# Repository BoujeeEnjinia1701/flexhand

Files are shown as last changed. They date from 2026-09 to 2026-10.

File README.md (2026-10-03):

# FlexHand

     

**Area:** BioMedical · **TRL:** 3 of 9 (proof of concept on paper) · **Value-engineering target:** USD 500 (estimated cost USD 305) · **Difficulty:** 4 of 5

Soft-actuated finger exoskeleton for continuous passive motion, driven by tendons from a wrist-mounted motor pack.

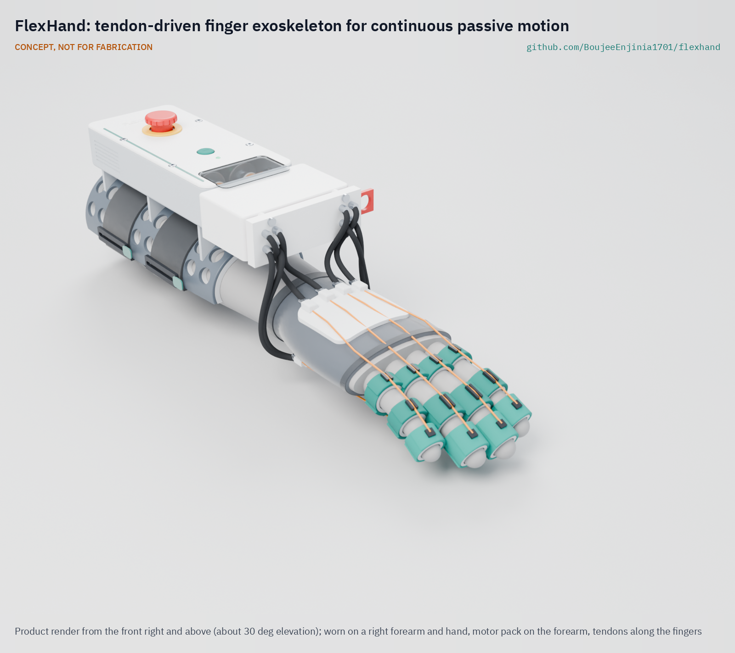
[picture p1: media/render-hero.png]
FlexHand: tendon-driven finger exoskeleton for continuous passive motion, product render


[Exploded render](media/render-exploded.png) · [Detail render](media/render-detail.png) · [Interactive 3D model](media/viewer.html) · [Concept blueprint (PDF)](media/concept-blueprint.pdf) · [General arrangement (PDF)](cad/drawings/FXH-DWG-001.pdf) · [Sizing calculations](docs/04-calcs/01-sizing.md) · [Prototype build plan](docs/05-build-plan.md) · [Design decisions](docs/06-design-decisions.md) · [Review note](docs/REVIEW.md)

## Concept rationale

Repetition is the scarce input in hand rehabilitation after stroke, and the scarce resource that delivers it is therapist time. A device that moves the fingers slowly through a therapist-set range, hundreds of times per session, can add dose at home without adding therapist hours. Tendons pulled through Bowden sheaths from a forearm pack keep the hand side light (about 117 g) and put the motors, cells and electronics where their mass matters least, which is why FlexHand uses tendons rather than a pneumatic glove or motors on the hand.

FlexHand is open and garage-buildable because the users who most need low-cost dose are least served by clinic-bound robotic gloves. Two off-the-shelf gearmotors, carrier-board electronics, 3D-printed TPU and PETG parts and bicycle shift housing keep the parts cost near USD 305 and let a research group, a clinic workshop or a makerspace build, inspect and adapt it. Openness also lets others check the safety layers (current limit, breakaway couplings, hardware stop and tool-free release) rather than trusting them. It is a research and educational prototype, not a medical device.

## Burning platform

Stroke is common, rising and concentrated where rehabilitation is thinnest. The Global Burden of Disease study counted 11.9 million new strokes and 93.8 million people living after a stroke in 2021, up 70 % and 86 % since 1990, with more than three-quarters of those affected living in low- and middle-income countries ([IHME, on the GBD 2021 stroke analysis in *The Lancet Neurology*, 2024](https://www.healthdata.org/news-events/newsroom/news-releases/lancet-neurology-air-pollution-high-temperatures-and-metabolic)). In many of those settings there are fewer than 10 skilled rehabilitation practitioners per million people ([WHO rehabilitation fact sheet](https://www.who.int/news-room/fact-sheets/detail/rehabilitation)).

Even where therapists are available, the dose is small. An observational study of 312 therapy sessions found an average of 32 repetitions of upper-limb functional movement per session, against the 400 to 600 repetitions per session used in animal studies of motor skill learning ([Lang et al., *Archives of Physical Medicine and Rehabilitation*, 2009](https://www.archives-pmr.org/article/S0003-9993(09)00353-0/abstract); [open copy, Marquette University](https://epublications.marquette.edu/cgi/viewcontent.cgi?httpsredir=1&article=1073&context=phys_therapy_fac)).

## Where it could be used

### By industry

| Industry | Use |
| --- | --- |
| Rehabilitation research | An open, instrumented platform for studies of passive-motion dose, speed and dwell, with logged cycle counts and motor current |
| Community and home rehabilitation services | A research prototype for supervised home programs, set up by a therapist and run by a care partner |
| Occupational and physical therapy education | A teaching device for tendon mechanics, joint range and the safety layers of powered orthoses |
| Assistive technology makerspaces | A documented build that local workshops can adapt to a hand, a glove size or local parts |
| Wearable robotics and medical device R&D | A low-cost reference design for tendon routing, balance pulleys and cuff pressure checks |

### By country or region

| Country or region | Why it matters there |
| --- | --- |
| United States | More than 795,000 people have a stroke each year, and stroke is a leading cause of serious long-term disability ([CDC](https://www.cdc.gov/stroke/data-research/facts-stats/index.html)); home programs could extend short outpatient courses. |
| Canada | Continuous passive motion was conceived at the Hospital for Sick Children in Toronto and has since been translated into clinical use around the world ([Canadian Medical Hall of Fame](https://www.cdnmedhall.ca/laureates/robertsalter)); an open device lets research groups in the country where the idea began build on it. |
| China | An upper-middle-income country among the low- and middle-income countries that carry more than three-quarters of the global stroke burden ([IHME](https://www.healthdata.org/news-events/newsroom/news-releases/lancet-neurology-air-pollution-high-temperatures-and-metabolic)); a large domestic electronics and motor supply base suits locally built open devices. |
| India | A WHO Systematic Assessment of Rehabilitation Situation review found that stroke units are clustered in metropolitan cities and tertiary centers and nearly absent at primary and secondary facilities ([Handa et al., *Current Physical Medicine and Rehabilitation Reports*, 2023](https://link.springer.com/article/10.1007/s40141-023-00418-2)); supervised home dose could reach people far from those centers. |
| Sub-Saharan Africa (for example Nigeria or Kenya) | Many low- and middle-income settings have fewer than 10 skilled rehabilitation practitioners per million people ([WHO](https://www.who.int/news-room/fact-sheets/detail/rehabilitation)), so each therapist's time must go further. |
| Brazil | In the 2019 National Health Survey, only 24.6 % of people who had had a stroke reported access to rehabilitation, and 73.4 % of those with activity limitations had received no physiotherapy ([Silva et al., *Arquivos de Neuro-Psiquiatria*, 2024](https://pmc.ncbi.nlm.nih.gov/articles/PMC11661889/)); a low-cost device that local university groups can build and study fits that gap. |

## What sparked the idea

The idea traces back to continuous passive motion, the concept Robert Salter developed in 1978 at the Hospital for Sick Children in Toronto after seeing how immobilization after surgery prolonged pain and recovery ([Canadian Medical Hall of Fame](https://www.cdnmedhall.ca/laureates/robertsalter)). His concept has since been translated into clinical applications around the world. FlexHand asks what that principle looks like as a light, open, wearable device that moves four fingers at home, within limits a therapist sets.

## Problem

Post-stroke hand rehab needs many repetitions, but therapist time is limited.

Problem statement: [docs/01-problem.md](docs/01-problem.md)

## Concept

Soft-actuated finger exoskeleton for continuous passive motion, driven by tendons from a wrist-mounted motor pack.

A fingerless glove carries TPU cuffs on the four fingers. Two gearmotors lying along the forearm in a strapped-on pack each turn a two-groove spool that pulls the flexor tendons of a finger pair while paying out the extensor tendons, through Bowden sheaths that cross the wrist. A floating balance pulley shares each spool line equally between the two fingers of a pair, and an open-tip fingertip thimble shares the extensor load with the finger cuff. The TRL 3 calculations give about 445 finger cycles per hour at full speed, about 3.8 sessions of 60 min per charge, cuff pressures of 40 kPa or less on a medium hand and an estimated USD 304.90 in parts, USD 195.10 under the USD 500 value-engineering target. One requirement is not met (forearm pack mass, about 712 g against 450 g), and two are at risk (gearbox rating and force-limit friction spread); see the [sizing calculations](docs/04-calcs/01-sizing.md) and the [review note](docs/REVIEW.md).

Full design precis: [docs/02-concept.md](docs/02-concept.md)

## Key components

- Two 25 mm 227:1 gearmotors with encoders, antagonistic spools and idlers
- Bowden sheaths and UHMWPE tendons, with balance pulleys, ball-detent breakaway couplings, stop beads and a pull-out release plate
- Fingerless glove, TPU finger cuffs and fingertip thimbles, dorsal and palmar plates, thumb spacer
- Motor drivers with current sensing for force limiting
- ESP32-S3 controller with a 5 V regulator, 2S Li-ion pack, emergency stop

The priced bill of materials is in [bom/bom.csv](bom/bom.csv). The parametric model is `cad/src/model.py` (STEP and STL in `cad/step` and `cad/stl`).

## Building the prototype

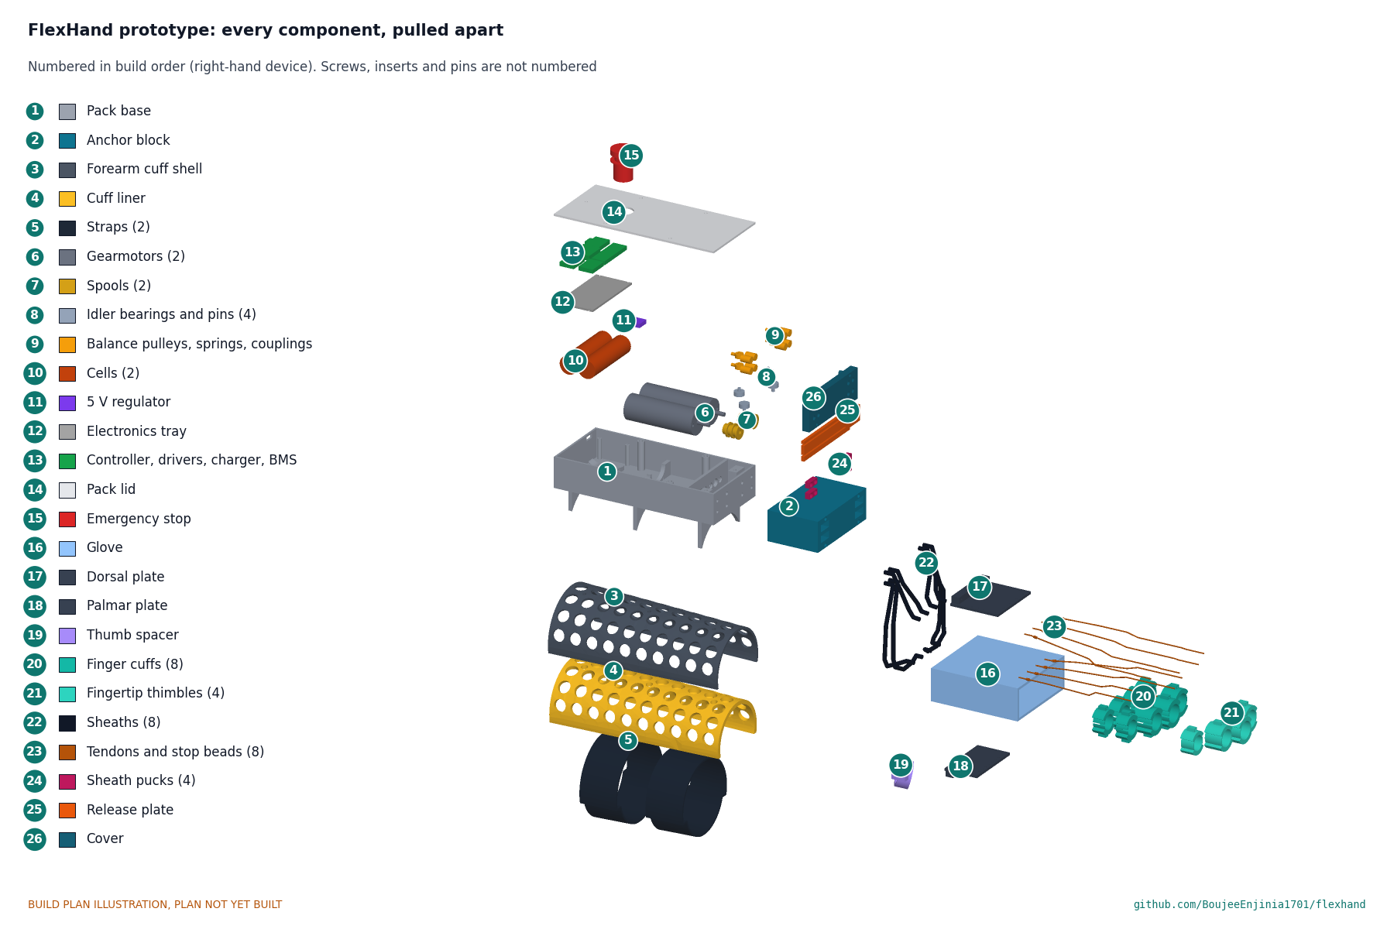
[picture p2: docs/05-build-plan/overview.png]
FlexHand prototype: every component, pulled apart and numbered in build order


The [prototype build plan](docs/05-build-plan.md) shows how to make each of the 26 components and put them together in 15 illustrated steps, with first checks and safety stops; it is a plan, not a record of a build. Drawing it made the design constructable: the pack is now screwed to the cuff, the motors sit in a printed bulkhead, the electronics sit on a tray, and a longer anchor block holds the balance pulleys and breakaway couplings, with a pull-out plate as the tool-free release ([FXH-DDR-003](docs/decisions/0003-design-for-construction.md)). Decisions still open are kept in the [design decisions register](docs/06-design-decisions.md).

## Safety

> This is a research and educational prototype. It is not a medical device, has not been cleared or approved by any regulator, and must not be used to diagnose, treat or monitor any person.

> **Safety:** The device applies force to fingers that may be spastic or insensate, its gearboxes cannot be back-driven, and it carries a lithium-ion pack. See the safety section of the [design precis](docs/02-concept.md) before building or wearing anything.

## Repository layout

| Folder | Contents |
| --- | --- |
| `docs/` | Problem, concept, requirements, calculations and design decisions |
| `cad/src/` | build123d Python source, the source of truth for all geometry |
| `cad/step/`, `cad/stl/` | Exported models for FreeCAD, other CAD tools and printing |
| `cad/drawings/` | 2D sketches and dimensioned drawings |
| `bom/` | Bill of materials |
| `electronics/` | KiCad schematics and PCB layouts |
| `firmware/` | Microcontroller code |
| `media/` | Renders, perspectives and photos |
| `build-log/` | Dated prototyping notes |

## Documentation

Controlled documents follow the portfolio [documentation standard](.kit/STANDARDS.md). Each carries a document ID (FXH-PRC-001 for the precis), a version and a revision history. Branded PDFs are built with `python .kit/render.py` and attached to GitHub Releases when a document is tagged, for example `FXH-PRC-001/v1.0`.

## Credits

Designed by Amish Chadha, with contributions from Dr. Geeti Chadha. See [CONTRIBUTORS.md](CONTRIBUTORS.md) for roles. To cite this design, use [CITATION.cff](CITATION.cff) (GitHub shows it as "Cite this repository").

AI assistance (Claude) was used to accelerate concept renders, prototype documentation and first-pass sizing calculations. Design direction and all decisions are Amish Chadha's, recorded in this repository's decision records (`docs/decisions/`).

## Licenses

- **Hardware** (CAD, drawings, BOM, electronics): [CERN-OHL-S v2](LICENSE)
- **Software** (firmware, scripts, notebooks): [MIT](LICENSE-SOFTWARE)

A project of the [Design Molecule](https://designmolecule.com) lab.

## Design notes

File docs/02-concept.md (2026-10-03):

---
doc_id: FXH-PRC-001
title: FlexHand design precis
project: FlexHand
doc_type: Design precis
version: "0.7"
status: Draft
date: '2026-10-02'
author: Amish Chadha
license: CERN-OHL-S-2.0
revisions:
- version: "0.1"
  date: '2026-09-24'
  author: Amish Chadha
  change: Initial scaffold
- version: "0.2"
  date: '2026-09-25'
  author: Amish Chadha
  change: Populate to TRL 2 (architecture, first-order numbers, safety, media)
- version: "0.3"
  date: '2026-09-25'
  author: Amish Chadha
  change: TRL 3 update; decisions of FXH-DDR-001 recorded, motors turned along the forearm with idlers, numbers from FXH-CAL-001, parametric model and drawing FXH-DWG-001
- version: "0.4"
  date: '2026-09-25'
  author: Amish Chadha
  change: Recommendations accepted by Amish (DDR-002); fingertip thimbles, balance pulleys with stop beads, ball-detent couplings, perforated cuff; numbers from FXH-CAL-001 v0.2
- version: "0.5"
  date: '2026-10-01'
  author: Amish Chadha
  change: "Constructable design (FXH-DDR-003): pack, motor, electronics, anchor block and release changes; mass and cost from FXH-CAL-001 v0.3; cost against the value-engineering target"
- version: "0.6"
  date: '2026-10-02'
  author: Amish Chadha
  change: 'Decisions of 2026-10-02 (FXH-DEC-001): co-design partner; design for construction accepted; release pass mark, finger spread check and pack mass added to the safety section'
- version: "0.7"
  date: '2026-10-02'
  author: Amish Chadha
  change: "Mass savings tried: pack 712 g, cost USD 304.90; R7 still not met"
---

# FlexHand design precis

FlexHand is a fingerless glove with tendon cuffs on the four fingers, driven through Bowden sheaths by two gearmotors in a pack strapped to the forearm. Each motor turns a two-groove spool that pulls a flexor line while paying out the matching extensor line, and a floating balance pulley splits each line between the two fingers of a pair, so one motor moves a pair of fingers both ways with equal tension in each. The extensor load on each finger is shared by a cuff on the middle phalanx and an open-tip thimble on the fingertip. The TRL 3 calculations (FXH-CAL-001 v0.3) give about 445 finger cycles per hour at full speed, about 3.8 sessions of 60 min per charge and cuff pressures of 40 kPa or less on a medium hand. Value-engineering target: USD 500. Estimated cost of the constructable design: USD 304.90 (USD 195.10 under the target). The design misses one requirement: the forearm pack is about 712 g against 450 g (R7). The design is constructable (FXH-DDR-003) and its build is planned in FXH-BLD-001 (`docs/05-build-plan.md`). The force requirement and the force limit are at risk (R2, R3).

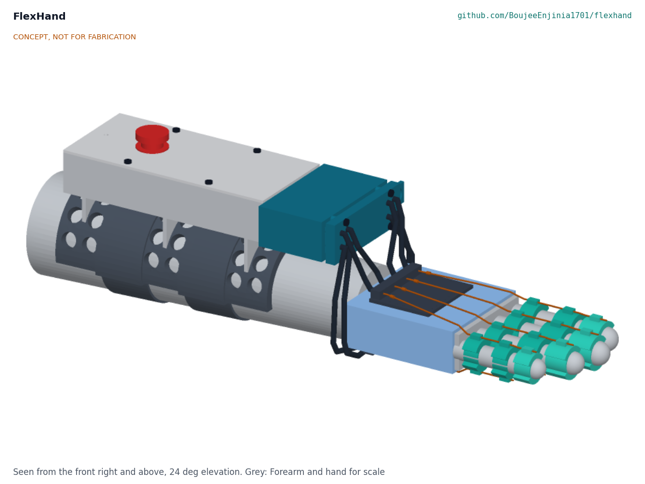
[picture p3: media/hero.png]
Hero render


*Figure 1. FlexHand on a right forearm and hand, palm down. Device parts are colored; the grey forearm and hand are for scale.*

## How it works

1. **Set up.** A therapist sets range-of-motion end points, stroke time, dwell and force limit for each finger pair. The limits are stored on the controller and cannot be changed from the user's buttons.
2. **Don.** A care partner slides on the fingerless glove, closes the finger cuffs over the proximal and middle phalanges, slides the thimbles onto the fingertips, clips the thumb spacer and straps the pack to the forearm. The tendons clip into the anchor block at the front of the pack.
3. **Cycle.** On start, each gearmotor turns its spool one way to pull the palmar (flexor) tendons and close the fingers, pauses, then turns back to pull the dorsal (extensor) tendons and open them. Each spool line pulls a floating balance pulley in the anchor block, which shares the pull equally between the two finger tendons of the pair. The encoder tracks position against the set end points; a crimped stop bead on each finger tendon limits that finger's travel to its own range if its partner is held back.
4. **Limit.** The motor drivers report current, which is roughly proportional to the combined tendon force of a finger pair. Because the balance pulley keeps both tendons at the same tension, the pair limit is also a per-finger limit. If force passes the limit, the motor stops and backs off. A ball-detent breakaway coupling on each tendon separates if force exceeds about 60 N.
5. **Stop.** A red latching stop button on the pack lid cuts motor power. A red release plate on the anchor block, pulled out by its finger loop, frees all tendons by hand, because the high-ratio gearboxes hold their position when unpowered.
6. **Log.** The controller records session time, cycle count and peak current for the therapist.

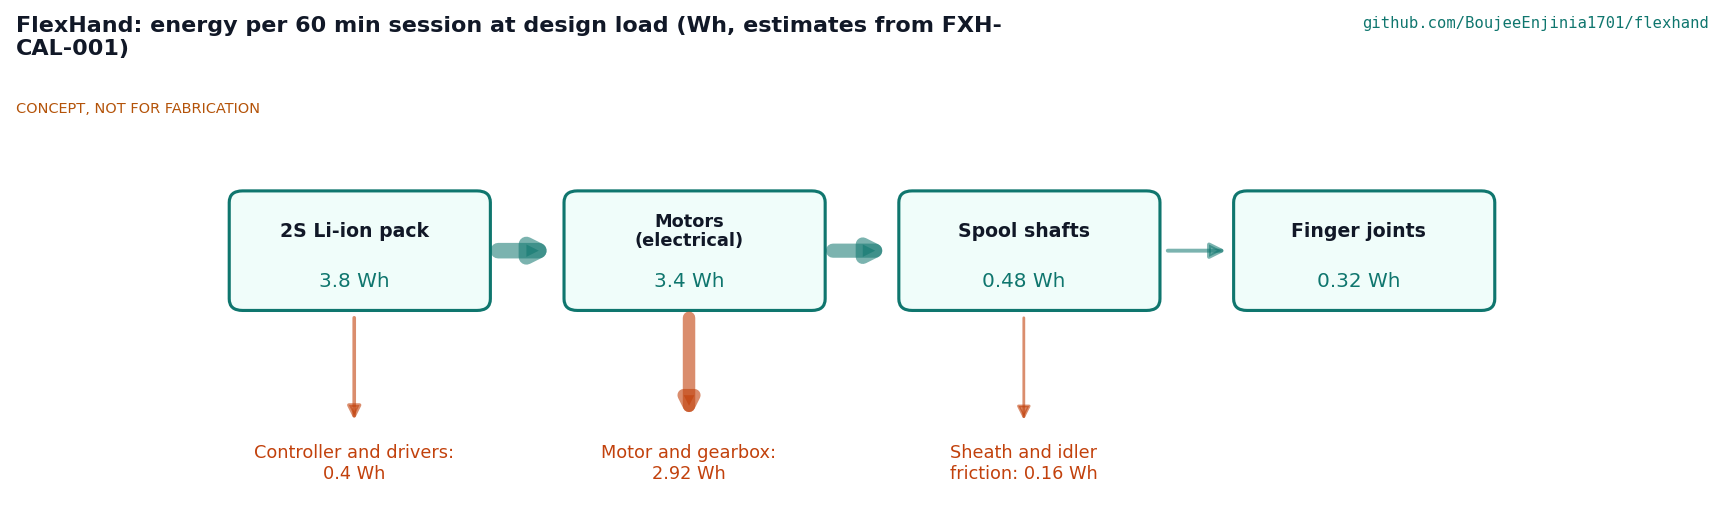
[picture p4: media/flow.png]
Energy flow


*Figure 2. Energy flow for one 60 min session at the design load, in Wh, from FXH-CAL-001. All values are estimates.*

## Main components

Numbers match the exploded view (Figure 3), drawing FXH-DWG-001 and `bom/bom.csv`.

Table 1. Main components.

| # | Component | Choice | Notes |
| --- | --- | --- | --- |
| 1 | Forearm cuff | 3D-printed PETG half shell, 2 mm, perforated with 12 mm holes (33 % open), with a matching 4 mm EVA foam liner and two 38 mm hook-and-loop straps | Spreads the pack load over the dorsal forearm; perforation saves about 25 g and ventilates the skin (N4) |
| 2 | Pack base | 3D-printed PETG, 168 x 76 mm, 2 mm walls, three saddle ribs with screw bosses, motor bulkhead and cradle, cell saddles, idler post and shelf | Screwed to the cuff with six M3 screws (DDR-003) |
| 3 | Gearmotors (2) | 25D x 71L mm, 227:1, 12 V rated, 48 CPR encoder (Pololu 4869), run at 7.2 V | Axes along the forearm at 15 mm each side of center (D1) |
| 4 | Spools (2) | Two-groove spool, 10 mm core, 14 mm flanges, 4 mm set-screw hub, 16 mm long | Flexor wound one way, extensor the other |
| 5 | Li-ion pack | Two 2,500 mAh 18650 cells across the rear of the pack, with 2S protection board | 18 Wh (D8) |
| 6 | Controller | ESP32-S3 module (Seeed XIAO ESP32S3 class) | Limits, logging, optional Bluetooth for the therapist view |
| 7 | Motor drivers (2) | DRV8874 H-bridge with current-sense output | Force limit through motor current |
| 8 | Pack lid | 3D-printed PETG, 2 mm, with stop button opening and LED window | |
| 9 | Emergency stop | 16 mm latching mushroom switch in the motor supply, between the cells and the motors | Hardware cut, not a firmware input |
| 10 | Sheath anchor block | Printed block 53 x 88 x 31 mm with four channels holding the balance pulleys, slack springs and eight ball-detent breakaway couplings; a cover with four sheath pucks; a red pull-out release plate; four slack springs; eight tendon stop beads at the hand end | Tool-free release (R9); ball-detent couplings save 40 g against magnets (N4); layout per DDR-003 |
| 11 | Bowden sheaths (8) | PTFE-lined 4 mm housing, about 80 mm (extensors) and 145 to 165 mm (flexors) | Carry tendons across the wrist so wrist posture does not change finger position much |
| 12 | Base glove | Fingerless, breathable, three sizes | Carries the plates; palm left mostly open |
| 13 | Dorsal plate | TPU 95A, 2.5 mm, with a stop block for the four extensor sheaths; stitched to the glove | |
| 14 | Palmar plate | TPU 95A, 2.5 mm, with a stop block for the four flexor sheaths; stitched to the glove | |
| 15 | Finger cuffs (8) | TPU 95A padded saddles with thin side bands, eyelets and a hook-and-loop closure, 2 mm padded liner: 12 mm guide cuffs on the proximal phalanges, anchor cuffs 12.2 to 18.6 mm wide on the middle phalanges | Anchor cuffs are as wide as the phalanx allows (D4) |
| 16 | Tendons (8) | 0.8 mm braided UHMWPE line | One flexor and one extensor per finger |
| 17 | Thumb spacer | TPU ring and web block, the block stitched to the glove | Holds the thumb abducted, out of the fingers' path (D6) |
| 18 | USB-C charger | 2S charger module in the rear of the pack | Charge only when not worn |
| 19 | Wiring and consumables | Wire, connectors, fasteners | Not modeled |
| 20 | Idler bearings (4) | 623ZZ class, 10 mm, axis vertical | Turn each spool line toward the anchor block |
| 21 | Fingertip thimbles (4) | Open-tip TPU 95A band, 2 mm, with 2 mm padded liner, 13.2 to 19.0 mm wide on the distal phalanges | Shares the extensor load with the anchor cuff; brings every finger under 50 kPa (N2) |
| 22 | Balance pulleys (4) | 693ZZ class, 8 mm, floating in the anchor block channels with 30 mm of travel | One per spool line; equal tension in both fingers of a pair (N3) |
| 23 | Electronics tray | Printed PETG plate over the cells carrying the modules | Holds the cells down (DDR-003) |
| 24 | Fixing kit | Heat-set inserts, M3 and M2.2 screws, 3 mm steel pins | Every joint has a fixing (DDR-003) |
| 25 | 5 V regulator | Step-down module, 5 V 1 A | Supplies the controller, which cannot take the pack voltage (DDR-003) |

Motor 1 drives the index and middle fingers and its sheaths run on the thumb (radial) side; motor 2 drives the ring and little fingers on the ulnar side.

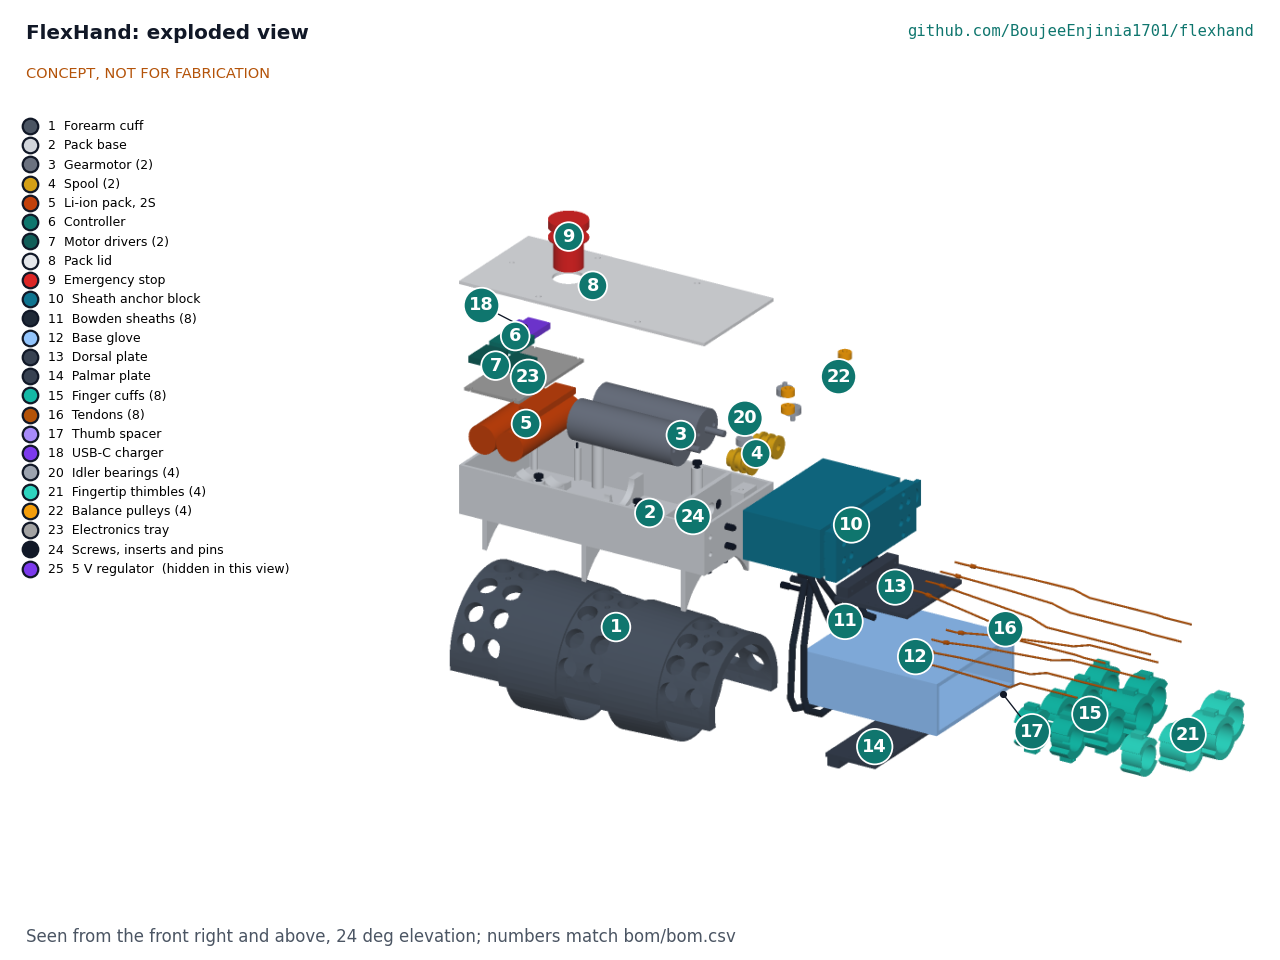
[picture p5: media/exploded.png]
Exploded view


*Figure 3. Exploded view with callouts matching `bom/bom.csv`. Line 19 of the BOM (wiring and consumables) is not modeled.*

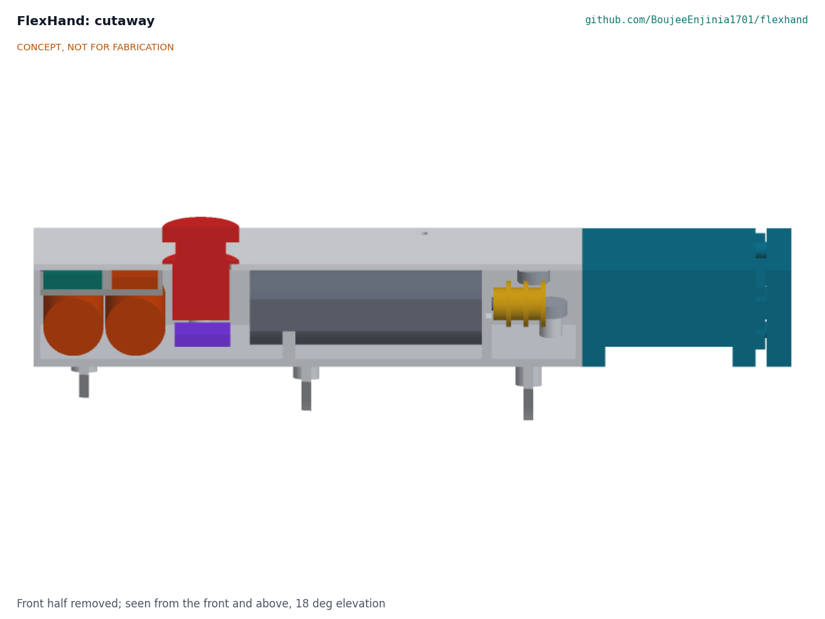
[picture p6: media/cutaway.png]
Cutaway


*Figure 4. Section through the motor pack on its centerline, seen from the side: cells with the electronics tray above them at the rear (left), the emergency stop, one gearmotor with its spool and idlers, and the anchor block at the front (right). The balance pulleys sit in channels 31.25 mm either side of the section plane and are not cut; the regulator (purple) sits beside the stop button.*

## TRL 3 numbers

All values are estimates from FXH-CAL-001; the tags in brackets are the script's output lines.

Table 2. Key numbers.

| Quantity | Value | Requirement |
| --- | --- | --- |
| Tendon excursion needed, stroke | 24.8 mm, 29.8 mm [A1], [A2] | R1 met |
| Design load | 30 N per finger; a MAS 1+ finger needs about 18 N [B1] | R2 restated for mild tone (N1) |
| Transmission efficiency | 0.659 (0.445 pessimistic), with the balance pulley [C1] | |
| Peak spool torque | 0.492 N·m, 125 % of the gearbox's continuous rating, 63 % of intermittent; RMS 0.269 N·m [C2], [C4] | R2 at risk |
| Force limit | 0.57 A trip; 40 N per finger with the balance pulley; 27 to 47 N friction spread [E1] to [E3] | R3 at risk |
| Stroke and cycle | Extension 3.31 s, flexion 2.78 s, cycle 8.08 s [D2] | R5 met (4 to 15 s at design load) |
| Repetitions | 445 per hour at full speed; 360 at 4 s strokes [D3], [D5] | R4 met |
| Energy per session | 3.80 Wh; 3.8 sessions per 18 Wh charge [F2], [F3] | R6 met |
| Mass on the hand | 117 g [G4] | R7 hand part met |
| Mass of forearm pack | 712 g [G2] | **R7 not met** |
| Cuff and thimble contact pressure | 23 to 40 kPa medium hand; 46 kPa worst on a small hand [H2], [H3] | R11 met on paper |
| Stop time | About 11 ms [I1] | R9 not verifiable at TRL 3 |
| Parts cost | USD 304.90 [J1] | R12: USD 195.10 under the USD 500 value-engineering target |

## Key design choices

Amish decided D1 to D8 on 2026-09-25 (FXH-DDR-001) by accepting the TRL 2 recommendations, and N1 to N5 later the same day by accepting the TRL 3 recommendations (FXH-DDR-002).

- **Tendons and Bowden sheaths rather than pneumatic soft actuators (D7).** Tendons need no pump or valves, run from a small battery and keep the hand light. The Columbia orthosis and Exo-Glove Poly show that tendon drives work for this task.
- **Two motors, one per finger pair, each with an antagonistic spool (D2).** One motor per pair moves the fingers both ways. Flexor and extensor excursions differ by about 1.2 mm, which a slack spring on each tendon in the anchor block takes up.
- **25 mm gearmotors on the forearm (D1).** The micro (N20) route could not carry the torque, and a bench-top unit departs from the wrist-mounted pitch. The 25 mm motors are the main cause of the R7 overrun, and the 450 g target is to be revisited with a therapist.
- **Motors along the forearm (TRL 3 layout).** At TRL 2 the motors lay across the forearm, but a 71 mm gearmotor with its spool needs about 84 mm, which forced a pack wider than the forearm. Turning the motors to lie along the forearm, with the spools at the front and a small idler turning each tendon pair forward, gives a 76 mm wide pack. The idlers cost about 5 % in efficiency.
- **Passive motion only (D3).** An active-assist mode triggered by the user's own effort is recorded as a later option; it is not part of this design.
- **Anchor cuffs as wide as the phalanx allows (D4), plus a fingertip thimble (N2).** The 20 mm cuff recommended at TRL 2 does not fit on any middle phalanx with clearance for PIP flexion. The extensor tendon runs on past the anchor cuff to an open-tip thimble on the distal phalanx, so the two share the load and the worst pressure falls from 84 to 40 kPa. The thimble is open at the tip to keep the fingertip free and to save mass.
- **Balance pulleys (N3).** A floating pulley on each spool line makes both fingers of a pair carry equal tension, so the current limit acts per finger (worst case 40 N, was 80 N). It costs about 5 % in efficiency and lengthens the anchor block from 12 to 44 mm (53 mm in the constructable design, which also holds the couplings and springs). A stop bead on each finger tendon keeps a free finger within its range when its partner is held back.
- **Lighter pack parts (N4).** Ball-detent breakaways and a perforated cuff save about 65 g. The pack is still about 712 g in the constructable design (723 g before the savings of 2026-10-02, 639 g before the fixings, bulkhead, tray and longer anchor block were added); the 450 g target stays under review with the co-design therapist, who treats the pack's load on a weak arm and shoulder as a safety question, and the listed mass savings were tried on 2026-10-02 (FXH-DEC-001) and took off 11 g, so the gap to the target is still 262 g.
- **Mild tone first, 4 s lower stroke limit (N1, N5).** R2 names mild flexor tone (MAS 1 to 1+), which the 30 N design load covers. The lower stroke limit at design load is 4 s, which the drive reaches even with pessimistic friction and which is gentler on the joints.
- **Thumb passive (D6).** A spacer holds the thumb abducted.
- **Force limiting in three layers.** Firmware current limit, a mechanical breakaway coupling on each tendon, and a hardware stop switch with a manual tendon release.
- **2S Li-ion pack (D8).** Enough for about 3.9 sessions and charged by USB-C. The portfolio's 48 V SwapCell pack is far larger than needed and is not used.

## Safety

> **Safety:** FlexHand is a research and educational prototype. It is not a medical device, has not been cleared or approved by any regulator, and must not be used to diagnose or treat any person. Any use on a person needs a supervising therapist, informed consent and, in a research setting, ethics review.

- **Joint injury.** Forcing a spastic or contracted finger can injure joints, tendons or skin. Range limits and force limits are set by a therapist, start low, and are enforced in firmware with a mechanical breakaway as backup. Movement is slow (30 °/s or less; about 28 °/s at the PIP at the fastest setting) to avoid provoking a stretch reflex. The balance pulleys hold both fingers of a pair to the same tension, but sheath friction still spreads the real force from about 27 to 47 N at a 40 N setting (R3 at risk). If one finger is held back, the balance pulley lets its partner move further; the stop bead on each tendon must be set to that finger's range before use.
- **Reduced sensation.** Many users cannot feel pressure or pain in the affected hand. Check the skin under every cuff before and after each session, and stop at any redness that does not fade within 30 min. R11 is met only on paper, under an assumed load sharing between cuff and thimble, so this design must not be worn until pressure has been mapped on a bench.
- **Entrapment.** The gearboxes hold their position when unpowered. If power fails with the fingers flexed, the hand stays closed until the tendons are released. The release plate and a care partner within reach are required. Its pass mark is set before the TRL 4 test: all tendons slack in 10 s or less, with a pull force the co-design therapist agrees a care partner can apply with one hand; a cam lever driving the same plate is the fallback.
- **Finger spread.** The cuffs hold the fingers slightly spread, which spastic fingers may resist. Nothing is worn until the co-design therapist has checked the spread on a range of hands with mild tone; if it raises tone or causes discomfort, the cuffs change to single saddles that fit fingers at rest.
- **Pack mass.** The forearm pack (about 712 g) loads a weak arm and shoulder; the co-design therapist reviews it as a safety question before anything is worn.
- **Pinch points and moving parts.** Spools, idlers and tendons are inside the pack; keep the lid closed while powered. Keep hair and loose clothing away from the tendon path.
- **Lithium-ion cells.** Use a protected 2S pack, charge only when not worn, on a non-combustible surface, and stop using a pack that is swollen, damaged or hot.
- **Electrical.** The pack runs at 8.4 V or less; there is no mains connection while worn.
- **Data.** Session logs are health data. Keep them on the device and the therapist's computer; share only with consent.

## Constructable design

Drawing the build plan showed parts of the concept that could not be made or fixed as drawn. FXH-DDR-003 records the changes made under Amish's 2026-09-30 instruction to make the design physically buildable: the pack is screwed to the cuff, the motors are held by a printed bulkhead, the electronics sit on a tray with a 5 V regulator added, the anchor block is 53 mm long with room for its pulleys, couplings and springs, the quick release is a pull-out plate, and the finger cuffs are padded saddles that fit side by side. What FlexHand does is unchanged. Amish accepted these changes on 2026-10-02, with the release pass mark and the finger spread check above.

## Open questions

Open decisions are listed in the design decisions register (`docs/06-design-decisions.md`, FXH-DEC-001), All of them were decided on 2026-10-02. The first clinical co-design partner is a university rehabilitation lab attached to a stroke service, introduced through the OpenRatio network; first candidate to approach: Shirley Ryan AbilityLab in Chicago, or a university rehabilitation program nearer Irving.

Concept media: [blueprint sheet](../media/concept-blueprint.pdf), [interactive 3D model](../media/viewer.html). General arrangement: [FXH-DWG-001](../cad/drawings/FXH-DWG-001.pdf).

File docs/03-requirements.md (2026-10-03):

---
doc_id: FXH-REQ-001
title: FlexHand requirements
project: FlexHand
doc_type: Requirements
version: "0.7"
status: Draft
date: '2026-10-02'
author: Amish Chadha
license: CERN-OHL-S-2.0
revisions:
- version: "0.1"
  date: '2026-09-24'
  author: Amish Chadha
  change: Initial scaffold
- version: "0.2"
  date: '2026-09-25'
  author: Amish Chadha
  change: First measurable requirements for TRL 2, with concept status
- version: "0.3"
  date: '2026-09-25'
  author: Amish Chadha
  change: TRL 3 status from FXH-CAL-001; decisions of FXH-DDR-001 applied (design load kept, R7 target kept pending therapist review, 20 mm cuff limit)
- version: "0.4"
  date: '2026-09-25'
  author: Amish Chadha
  change: Recommendations accepted by Amish (DDR-002); R2 reworded to mild tone, R5 lower limit 4 s at design load, status from FXH-CAL-001 v0.2
- version: "0.5"
  date: '2026-10-01'
  author: Amish Chadha
  change: Status from FXH-CAL-001 v0.3 for the constructable design (FXH-DDR-003); R12 reported against the value-engineering target
- version: "0.6"
  date: '2026-10-02'
  author: Amish Chadha
  change: 'Decisions of 2026-10-02 (FXH-DEC-001): R9 release pull force agreed with the therapist before the test; R7 pack target reviewed as a safety question; no wearing before the finger spread check. No status changed'
- version: "0.7"
  date: '2026-10-02'
  author: Amish Chadha
  change: "R7 value updated to 712 g after the mass savings tried on 2026-10-02; status unchanged (not met)"
---

# FlexHand requirements

These requirements are checked by calculation in FXH-CAL-001 v0.3, for the constructable design of FXH-DDR-003. Seven are met on paper, two are at risk (R2 and R3), one is not met (R7, forearm pack mass) and three cannot be verified until TRL 4. On 2026-09-25 Amish accepted the recommendations raised by the TRL 3 calculations (FXH-DDR-002): R2 now names mild flexor tone (N1), and the lower end of the R5 stroke-time range is 4 s at design load (N5). The fingertip thimble (N2), the balance pulleys (N3) and the lighter couplings and perforated cuff (N4) are in the design. The 450 g pack target stays until a therapist has reviewed it, which waits on the choice of a clinical co-design partner (FXH-DDR-001, D1 and O1).

Table 1. Requirements and TRL 3 status.

| ID | Requirement | Target | Verification | TRL 3 status (FXH-CAL-001) |
| --- | --- | --- | --- | --- |
| R1 | Move the four fingers through a useful range | MCP 0 to 70°, PIP 0 to 90°, within therapist-set limits | Tendon excursion calculation; later bench test on a finger model | Met: 24.8 mm excursion needed, 29.8 mm stroke |
| R2 | Extend fingers against mild flexor tone (MAS 1 to 1+) (N1) | 30 N extensor tendon force per finger at the finger | Torque and friction calculation; published stiffness data | **At risk:** 30 N covers the 18 N a MAS 1+ finger needs; 0.492 N·m peak at the spool, 125 % of the gearbox's recommended continuous load (RMS 68 %, peak 63 % of intermittent) |
| R3 | Limit force on the hand | Software limit 40 N per finger from motor current; mechanical breakaway at 60 N or less per tendon | Calculation; later bench test | **At risk:** the balance pulleys (N3) keep both fingers of a pair at equal tension, so the pair limit holds each finger to 40 N (was up to 80 N); friction still spreads the force from 27 to 47 N at a 40 N setting |
| R4 | Deliver a high repetition dose | 300 or more full flexion and extension cycles in a 60 min session | Speed calculation | Met: 445 cycles per hour at full speed; 360 at the 4 s lower stroke limit; holds for strokes up to 5 s |
| R5 | Move slowly and smoothly | Stroke time adjustable from 4 to 15 s at design load (N5), down to 3 s at lighter loads; joint speed 30 °/s or less; dwell at each end adjustable | Speed calculation; firmware sketch | Met: fastest stroke at design load 3.3 s (3.9 s with pessimistic friction; 2.6 s unloaded) |
| R6 | Run several sessions per charge | 3 or more 60 min sessions at design load | Power budget | Met: 3.8 sessions at 3.80 Wh each |
| R7 | Light enough to wear seated | Hand-side parts 120 g or less; forearm pack 450 g or less (pack target to be revisited with a therapist, D1, treating the pack's load on a weak arm and shoulder as a safety question; decided 2026-10-02) | Mass estimate, then weighing | **Not met:** hand 117 g (met); pack 712 g in the constructable design (639 g in the concept, 675 g before N4) |
| R8 | Quick to put on and take off | A care partner dons it in 5 min or less and removes it in 1 min or less | Design review with users | Not verifiable at TRL 3; at risk on flexed, spastic fingers |
| R9 | Stop and release on demand | Physical stop cuts motor power within 100 ms; tendons released by hand in 10 s or less without tools, with a pull force that the co-design therapist agrees, before the TRL 4 test, a care partner can apply with one hand (decided 2026-10-02) | Calculation; later bench test | Not verifiable at TRL 3: stop in about 11 ms by calculation; release time needs a bench test |
| R10 | Fit most adult hands | Hand length 170 to 205 mm with three glove sizes and adjustable cuffs | Anthropometric check | Met on paper: sizes scaled 0.95, 1.00 and 1.15 from the model |
| R11 | Keep contact pressure tolerable | Mean pressure under a finger cuff or thimble 50 kPa or less at design load (proposed limit, to be set with a therapist) | Contact area calculation | Met on paper: 23 to 40 kPa on the medium hand, 46 kPa worst on a small hand's little finger, with the fingertip thimble sharing the load (N2; was 46 to 84 kPa); load sharing assumed, to check at TRL 4 |
| R12 | Low cost and buildable | Parts cost against the USD 500 value-engineering target (a control target, not a limit); no custom PCB for the first build | Priced BOM | Estimated cost USD 304.90, USD 195.10 under the target; no custom PCB |
| R13 | Record what was done | Device logs session time, cycle count and peak motor current; therapist limits cannot be changed from the user controls | Design review | Not verifiable at TRL 3: storage ample (1 MB holds decades of summaries) |

## Assumptions

- Design load: 30 N of extensor tendon force per finger at full extension (D5). Checked against the finger stiffness measured by [Heung et al., *Frontiers in Bioengineering and Biotechnology*, 2020](https://www.frontiersin.org/journals/bioengineering-and-biotechnology/articles/10.3389/fbioe.2020.00111/full): it covers a finger with MAS 1+ tone with a margin of about 1.7, not a finger with MAS 3 tone. It is consistent in scale with the Columbia orthosis, whose single motor provides about 100 N peak for four fingers ([Park et al., arXiv 1802.06131](https://arxiv.org/abs/1802.06131)).
- Tendon excursion for 70° at the MCP and 90° at the PIP is 24.8 mm, taking dorsal moment arms of 10 mm and 8 mm; the stroke adds 5 mm for cuff compliance.
- Transmission efficiency is 0.659: capstan friction with a coefficient of 0.1 over 180° of sheath bend, one idler at 95 % and one balance pulley at 95 %.
- The extensor load of each finger is shared by the middle-phalanx cuff and the fingertip thimble in proportion to their contact areas.
- The forearm rests on a support during sessions. The device is not designed to be worn while walking.
- Sessions are supervised by a care partner, at least until a therapist agrees otherwise.

> **Safety:** R3, R9 and R11 are safety requirements. A design that misses any of them must not be worn by a person, even at TRL 4 bench stage. R11 is met only on paper and R3 is at risk, so nothing may be worn on the strength of these numbers. Nothing is worn either until the co-design therapist has checked the finger spread the cuffs need on a range of hands with mild tone (FXH-DEC-001, 2026-10-02).

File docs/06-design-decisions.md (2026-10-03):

---
doc_id: FXH-DEC-001
title: FlexHand design decisions register
project: FlexHand
doc_type: Design decisions register
version: "0.3"
status: Draft
date: '2026-10-02'
author: Amish Chadha
license: CERN-OHL-S-2.0
revisions:
  - version: "0.1"
    date: '2026-10-01'
    author: Amish Chadha
    change: Register opened with the open decisions from the review note, FXH-DDR-001 to FXH-DDR-003 and the build plan work
  - version: "0.2"
    date: '2026-10-02'
    author: Amish Chadha
    change: 'Amish approved the recommendations for all five open decisions on 2026-10-02 (FXH-DDR-003 accepted); moved to decisions made; value engineering states that the mass savings cannot close the R7 gap'
  - version: "0.3"
    date: '2026-10-02'
    author: Amish Chadha
    change: 'Mass savings tried (11 g off the pack, 723 to 712 g); cost USD 304.90; R7 still not met'
---

# FlexHand design decisions register

Every design decision still to be made, and every decision made, in one place. Each decision is argued in full in its decision record under `docs/decisions/`; this register is the index Amish works from. The build plan (`docs/05-build-plan.md`) describes the design as it stands and does not list open decisions.

## Open decisions

None. All open decisions were decided on 2026-10-02.

## To confirm when parts are bought

| # | What to confirm | Why it matters | Source |
| --- | --- | --- | --- |
| 1 | The gearbox face's two M3 holes: spacing (17 mm assumed), how deep a screw may go, and the shaft length (12.5 mm assumed) | They set the bulkhead holes, the 6 mm screw length and how far the spool hub reaches onto the shaft | FXH-DDR-003, C3, C4 |
| 2 | The motor length with its encoder (71 mm assumed) and where the encoder cable leaves | Sets the 6 mm cable gap behind the motors | FXH-DDR-003, C5 |
| 3 | The stop button's body depth (18 mm assumed), bezel and nut | Its body sits between the cells and the motors | FXH-DDR-003, C5 |
| 4 | The sizes of the controller, driver, charger, battery board and regulator modules, and the charger's USB-C port position | They are laid out on the tray, and the port must meet the rear wall opening | FXH-DDR-003, C5 |
| 5 | The cells' length with any protection fitted (65 mm assumed) | The saddles and tray posts leave 0.5 mm at each end | FXH-DDR-003, C5 |
| 6 | The sheath housing's outside diameter (4 mm) and its ferrules' (about 5 mm) | They set the puck, stop block and cover holes | FXH-DDR-003, C7, C11 |
| 7 | The glove's size and stretch against the plate and spacer positions | Plates and spacer are stitched where the model puts them | FXH-DDR-003, C11, C12 |
| 8 | The breakaway couplings' pull-out force (about 60 N) and the stop-bead settings | Set and recorded at TRL 4 | FXH-DDR-002, N3, N4 |

## Value engineering

Value-engineering target: USD 500 (a hypothetical control target, not a limit). Estimated cost of the constructable design: USD 304.90 (USD 195.10 under the target), from `bom/bom.csv` [J1]. Main cost drivers and savings worth trying:

- **Gearmotors, USD 107.90 (36 %).** The largest line and 214 g of the pack's mass. Worth pricing a lighter 20 to 25 mm gearmotor class with encoder that still carries 0.49 N·m peak; any change reopens R2 and the torque calculation.
- **Battery, stop button and electronic modules, about USD 68.** Standard modules; little to save in cost, but a single dual-channel driver board would save one board, its wiring and a few grams.
- **Anchor block and its hardware, USD 18 plus fixings.** The printed parts are now 68 g, 3.4 g less after a larger lightening pocket (tried on 2026-10-02). A thinner-walled block with the channels as separate tubes, or printing it in a lighter material, remains to try.
- **Fixing kit, USD 11, 22 g.** Aluminium M3 screws now hold the lid and the cover (tried on 2026-10-02): 5.4 g saved for USD 1 more. The tray keeps steel self-tapping screws because aluminium ones are not made in that size.
- **Pack base, 103 g.** Saddle ribs thinned from 4 to 3 mm saved 2.6 g (tried on 2026-10-02). Lower infill is a print setting that saves little in 2 mm walls and is left to the TRL 4 prints; the motor torque reaction is checked there.

The savings tried on 2026-10-02 (decision 5) took 11.4 g off the pack, from 723 g to 712 g, and cannot close the 262 g gap to R7's 450 g target. R7 stays not met, and the therapist review of the target, which also treats the pack's load on a weak arm and shoulder as a safety question, decides it.

## Decisions made

| Date | Decision | Decided by | Record |
| --- | --- | --- | --- |
| 2026-09-25 | TRL 2 review items D1 to D8: 25 mm 227:1 gearmotors on the forearm, two motors, passive motion only, widest anchor cuffs with a soft liner, 30 N design load, passive thumb, tendons in Bowden sheaths, 2S pack | Amish: "proceed with all of your recommendations across all batches. Make sure we don't proceed to TRL 4 on any of them." | FXH-DDR-001 |
| 2026-09-25 | TRL 4 on hold for this repo | Amish, same instruction | `project.yaml` (trl_target), FXH-DDR-001 |
| 2026-09-25 | Items N1 to N5: R2 restated for mild tone, fingertip thimbles, balance pulleys with stop beads, ball-detent couplings and a perforated cuff, 4 s lower stroke limit at design load | Amish: "i accept all your recommendations, go with them across all repos." | FXH-DDR-002 |
| 2026-09-26 | FlexHand in the first batch of product renders | Amish chose the repo (no words recorded) | `docs/REVIEW.md`, session of 2026-09-26 |
| 2026-09-30 | Make the design physically buildable while drawing the build plan | Amish: "If you are realising that the design cannot be built as per concept - fix the design assumptions to match and be physically feasible as you draw the illustrations." | FXH-DDR-003 (changes made under this instruction; accepted on 2026-10-02, below) |
| 2026-09-30 | Outstanding decisions are kept in this register, not in the build plan | Amish: "don't log outstanding decisions in this build plan - that is not the place for it. that should be in a separate design document logged and named as such" | This register |
| 2026-10-01 | `budget_usd` is a value-engineering target, not a limit | Amish: "the budgets are a hypothethical control target to ensure we are thinking along a value engineering lens. its ok to ensure wording reflects that the hypothesis budget was x - the real cost being accrued is y" | This register, Value engineering |
| 2026-10-02 | First clinical co-design partner: a university rehabilitation lab attached to a stroke service, introduced through the OpenRatio network; first candidate to approach: Shirley Ryan AbilityLab in Chicago, or a university rehabilitation program nearer Irving | Amish: "i approve your recommendations for all 555 open decisions." | FXH-DDR-001, O1 |
| 2026-10-02 | Design for construction accepted: changes C1 to C14 and their knock-on changes, as made; the release (C7) and the finger spread (C10) are confirmed separately in the next two rows | Amish: "i approve your recommendations for all 555 open decisions." | FXH-DDR-003, Tables 1 and 2 |
| 2026-10-02 | Tool-free release: the pull-out plate (option a). Pass mark set before the TRL 4 test: released in 10 s or less (R9) with a pull force that the co-design therapist agrees, before the test, a care partner can apply with one hand; the cam lever (option b) is the fallback if it fails | Amish: "i approve your recommendations for all 555 open decisions." | FXH-DDR-003, A1 |
| 2026-10-02 | Finger spread: option (a), cuffs that hold the fingers slightly spread, but nothing is worn until the co-design therapist has checked the spread on a range of hands with mild tone; switch to single-saddle cuffs if the spread raises tone or discomfort | Amish: "i approve your recommendations for all 555 open decisions." | FXH-DDR-003, A2 |
| 2026-10-02 | Forearm pack about 723 g: keep the 450 g target of R7 under therapist review, treating the pack as a safety question for that review (load on a weak arm and shoulder), and try the listed mass savings before TRL 4 | Amish: "i approve your recommendations for all 555 open decisions." | FXH-DDR-003, A3; FXH-DDR-002, N4 |

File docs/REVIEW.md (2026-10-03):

# Review note: FlexHand

## Session 2026-09-25: /populate to a strong TRL 2 (overnight batch run)

### What was done

- `docs/01-problem.md` (FXH-PRB-001 v0.2): problem with cited evidence on hand impairment and therapy dose, prior devices (clinical gloves, NEOFECT, Columbia tendon orthosis, Exo-Glove Poly II), users and context, constraints, safety note, out of scope, open questions. There was no co-design checklist to keep.
- `docs/03-requirements.md` (FXH-REQ-001 v0.2): 13 measurable requirements (R1 to R13) with targets, planned verification, concept status and stated assumptions.
- `docs/02-concept.md` (FXH-PRC-001 v0.2): how it works, 17 numbered components, first-order numbers, key design choices with options, safety section, open questions.
- `cad/src/concept_media.py`: massing model of the forearm cuff, motor pack (two 25 mm gearmotors, spools, 2S cells, controller, drivers, lid, stop button), sheath anchor block, Bowden sheaths, glove, plates, finger cuffs, tendons and thumb spacer, on a grey forearm and hand for scale (no 1.75 m figure, as for TremorTrace). Modeled as a right hand and mirrored to a left hand so the thumb side faces the standard camera.
- `media/`: `hero.png`, `concept-blueprint.png`, `.pdf` and `.svg`, `exploded.png` (callouts 1 to 17), `cutaway.png` (motor pack only), `flow.png` (energy per session, all values estimates), `model.glb` and `viewer.html`.
- `bom/bom.csv`: 19 lines with indicative prices, lines 1 to 17 matching the exploded view; `bom/bom-notes.md` updated.
- `README.md`: hero image and links line before "## Problem"; concept paragraph, key components and a safety note brought in line with the concept.
- `docs/pdf/`: branded PDFs of the three controlled documents.
- `project.yaml` is unchanged; the pitch and problem still match the numbers found.

### Key results (estimates, to be checked at TRL 3)

| Quantity | Estimate | Requirement |
| --- | --- | --- |
| Extensor tendon force, design load | 30 N per finger (assumed), 0.41 N·m at the spool | R2 met, thin margin |
| Repetitions | about 6.4 cycles per min, about 385 per hour | R4 met |
| Sessions per charge (18 Wh 2S pack) | about 3.1 at 4.7 Wh per session | R6 met, no margin |
| Mass on the hand | about 90 g | R7 hand part met |
| Mass of forearm pack | about 510 g | **R7 not met** (450 g) |
| Cuff contact pressure | about 100 kPa with 12 mm cuffs | **R11 not met** (50 kPa) |
| Parts cost | about $280 | R12 met (budget $500 unchanged) |

Requirements not met or at risk:

- **R7 (pack mass) not met:** about 510 g against 450 g, driven by the two 25 mm gearmotors (about 190 g).
- **R11 (cuff pressure) not met:** about 100 kPa against a proposed 50 kPa. Wider (20 mm) cuffs would give about 43 kPa but may block PIP flexion.
- **R2 marginal:** peak spool torque is about 5 % above the gearbox maker's recommended continuous load, though within its intermittent limit.
- **R8 (donning time) at risk:** fitting cuffs on flexed, spastic fingers is unverified.
- **R6 no margin** at the design load.

### Proposed, awaiting Amish

Status update: items 1 to 7 and 9 were decided by Amish on 2026-09-25 (go with recommendation, FXH-DDR-001, D1 to D8). Item 8 has no recommendation and stays proposed, awaiting Amish (O1).

1. **Motor route (drives R2 and R7).** (a) 25 mm 227:1 gearmotors on the forearm, about 510 g pack; (b) micro (N20) gearmotors with the force target cut to 20 N per finger, lighter but weaker than moderate tone may need; (c) a bench-top motor unit with longer sheaths, very light on the arm but departs from the wrist-mounted pitch. Recommendation: (a) for the first build and revisit the 450 g target with a therapist, since the forearm rests on a support during sessions.
2. **Motor count.** One motor for four fingers, two motors (one per finger pair) or four motors. Recommendation: two.
3. **Passive only or plan for active assist (pitch-level).** Evidence for passive motion alone improving function is weak; an active-assist mode triggered by the user's effort would strengthen the case but adds sensing and scope. Recommendation: keep the pitch as passive motion for TRL 3 and record active assist as a later option.
4. **Cuff pressure fix.** Wider padded cuffs, a distal anchor, or a lower force limit. Recommendation: 20 mm cuffs with a soft liner, checked for PIP clearance at TRL 3.
5. **Design load.** 30 N per finger for mild to moderate flexor tone. Recommendation: keep, and check against published stiffness data.
6. **Thumb passive** with an abduction spacer. Recommendation: keep for TRL 3.
7. **Tendons through Bowden sheaths** rather than a pneumatic glove. Recommendation: tendons.
8. **First clinical co-design partner** (stroke unit OT team, community rehabilitation service or university lab).
9. **Pack voltage** 2S (7.4 V) with 12 V rated motors, trading speed for a smaller pack. Recommendation: keep.

### Safety concerns

- Not a medical device; every document says so and must keep saying so.
- Forcing spastic or contracted fingers: layered force limits (firmware current limit, 60 N breakaway, hardware stop) are designed but unverified.
- Non-back-drivable gearboxes can hold the hand closed on power loss; the tool-free quick-release and a care partner within reach are essential.
- Users may not feel pressure; R11 is not met, so nothing should be worn until cuff pressure is reduced.
- 2S lithium-ion pack worn on the arm: protected pack, no charging while worn.

### Problems and notes

- PMC pages were blocked by a bot check during research, so the passive-mobilization study is cited by title and link without detailed results.
- The 30 N design load is an engineering estimate, not a measured value; it drives most of the numbers.
- The legacy `cad/src/model.py` placeholder is untouched (TRL 3 work).
- The cutaway shows only the motor pack; the hand-side parts have nothing inside worth sectioning.

### Recommended next step

Review this note and the media, then decide items 1 and 3. If approved, run `/advance-trl3` to check the design load, torque, speed, power, mass and cuff pressure by calculation and produce the parametric model and drawing sheet.

## Session 2026-09-25: TRL 3

Amish reviewed the TRL 2 review points on 2026-09-25 and wrote: "proceed with all of your recommendations across all batches. Make sure we don't proceed to TRL 4 on any of them." This session ran `/advance-trl3` on that authority and stopped at TRL 3.

### What was done

- `docs/decisions/0001-trl2-review-decisions.md` (FXH-DDR-001 v0.1): the eight TRL 2 items with a recommendation recorded as "Decided by Amish, 2026-09-25: go with recommendation" (D1 to D8); the co-design partner left open (O1); five new items raised by the calculations (N1 to N5), proposed.
- `docs/04-calcs/01-sizing.md` (FXH-CAL-001 v0.1) and `docs/04-calcs/sizing.py`: excursion, design load against published finger stiffness, transmission and torque, motor speed and cycle, force limit, energy, mass, cuff pressure and fit, stop time, cost and log storage, with a results table for R1 to R13. The script imports the model and the BOM and prints every quoted number with a tag.
- `cad/src/model.py`: parametric build123d model (forearm cuff, pack, motors, spools, idlers, cells, electronics, stop button, anchor block, sheaths, glove, plates, cuffs, tendons, thumb spacer) on a forearm and hand context. Exports `cad/step/flexhand-assembly.step`, `flexhand-on-forearm.step` and nine part files, with matching STL files in `cad/stl/`.
- `cad/src/sheets.py` and `cad/drawings/FXH-DWG-001.svg`, `.pdf`, `.png`: forearm unit general arrangement at Rev P1, 1:2, with main dimensions and parts list, marked "CONCEPT, NOT FOR FABRICATION" and "PRELIMINARY, NOT FOR FABRICATION". The concept sheet keeps its number, FXH-DWG-010, so the general arrangement took FXH-DWG-001.
- `bom/bom.csv`: 20 lines, all priced, $281.90 against the $500 budget; line 20 (idler bearings) added; `bom/bom-notes.md` updated.
- `cad/src/concept_media.py` now builds the media from the model; all media in `media/` regenerated and checked by eye; temporary view folders removed.
- `docs/01-problem.md`, `docs/02-concept.md`, `docs/03-requirements.md` moved to v0.3 with the decisions and the TRL 3 numbers; `README.md` and `project.yaml` (trl: 3, trl_target: 3, trl_evidence) updated; PDFs rebuilt in `docs/pdf/`.
- Design change inside TRL 3 scope: the gearmotors now lie along the forearm with the spools at the front and idlers turning the tendons forward, because a 71 mm motor with its spool would not fit across a pack narrow enough for the forearm. The pack is 160 by 76 mm.

### Requirements (FXH-CAL-001), not met first

| ID | Status | Value against target |
| --- | --- | --- |
| R7 | **Not met** | Pack about 675 g against 450 g; hand 103 g against 120 g (met) |
| R11 | **Not met** | 46 to 84 kPa against 50 kPa; only the middle finger passes; 96 kPa on a small hand's little finger |
| R2 | At risk | 30 N delivered, but the 0.467 N·m peak is 119 % of the gearbox's continuous rating (RMS 65 %), and 30 N covers mild tone (MAS 1+) only; MAS 3 needs about 148 N |
| R3 | At risk | Current senses a finger pair: one finger can reach 80 N before a 40 N per finger limit trips (the 60 N breakaway acts first); friction spread -32 to +18 % |
| R5 | At risk | Fastest stroke at design load 3.3 s against 3 s |
| R1, R4, R6, R10, R12 | Met | 29.8 mm stroke; 448 cycles per hour; 3.9 sessions per charge; three sizes; $281.90 |
| R8, R9, R13 | Not verifiable at TRL 3 | Donning time; release time (stop time about 11 ms by calculation); limit lock |

Counts: 5 met, 3 at risk, 2 not met, 3 not verifiable at TRL 3. Numbers that changed from TRL 2: peak torque 0.41 to 0.467 N·m, cycles 385 to 448 per hour, sessions 3.1 to 3.9, pack mass 510 to 675 g, cuff pressure 100 kPa to 46 to 84 kPa.

### Decisions recorded (FXH-DDR-001)

Decided by Amish, 2026-09-25, going with the TRL 2 recommendations: D1 25 mm 227:1 gearmotors on the forearm, 450 g target to be revisited with a therapist; D2 two motors; D3 passive motion only, active assist a later option, pitch unchanged; D4 cuffs up to 20 mm with a soft liner, checked for PIP clearance (the check shows 20 mm does not fit; cuffs set to 12.2 to 18.6 mm); D5 30 N design load kept and checked against stiffness data; D6 thumb passive; D7 tendons in Bowden sheaths; D8 2S pack. The TRL 2 review recommended no change to the budget, pitch or problem line, so all three are unchanged. The SwapCell cross-cutting decisions do not apply (no SwapCell pack).

### Still awaiting Amish

- O1: first clinical co-design partner (no recommendation).
- N1: reword R2 to mild flexor tone (MAS 1 to 1+) or raise the design load. Recommendation: reword. Decided by Amish, 2026-09-25: go with recommendation (FXH-DDR-002).
- N2: fingertip thimble sharing the extensor load (23 to 40 kPa). Recommendation: add it. Decided by Amish, 2026-09-25: go with recommendation (FXH-DDR-002).
- N3: balance pulley so the current limit acts per finger. Recommendation: add it. Decided by Amish, 2026-09-25: go with recommendation (FXH-DDR-002).
- N4: pack mass: lighter breakaways, perforated cuff, therapist-agreed target. Recommendation: the first two, then the target review. Decided by Amish, 2026-09-25: go with recommendation (FXH-DDR-002); the target review waits on O1.
- N5: relax the lower stroke-time limit to 4 s at design load. Recommendation: relax. Decided by Amish, 2026-09-25: go with recommendation (FXH-DDR-002).

### Safety concerns

- Not a medical device; every document still says so.
- R11 is not met and R3 is at risk. Nothing may be worn until cuff pressure is reduced and the per-finger force limit is fixed; both are safety requirements.
- The design load suits mild tone only. Using it on fingers with moderate or severe tone would stall at the force limit, and raising the limit to compensate would overload the gearbox and the skin.
- The gearboxes hold position when unpowered: the tool-free release lever and a care partner within reach remain essential.
- Protected 2S lithium-ion pack worn on the arm: no charging while worn.

### Citations

- The passive-mobilization study, previously cited only by title because PMC showed a bot check, is now cited with authors, journal and year (Gobbo et al., *BioMed Research International*, 2017), confirmed by search. Its full text could not be fetched (PMC bot check, Wiley 403), so its detailed results are still not quoted.
- Motor data were checked on the Pololu 4869 specifications page (107 g, 24 kg·cm stall, 4 and 8 kg·cm recommended loads, $53.95).
- New citation: Heung et al., *Frontiers in Bioengineering and Biotechnology*, 2020, for finger joint stiffness after stroke (fetched and read).
- Phalanx length shares (47, 28 and 25 %) are stated as assumptions; the anthropometric source found (Buryanov and Kotiuk, 2010) could not be fetched, so it is not cited.

### Problems and notes

- No TRL 4 material exists in this repo (`electronics/`, `firmware/` and `build-log/` hold only the scaffold README), and none was created.
- The mean-pressure metric for R11 ignores skin shear and edge pressure; the cuff design needs a bench check at TRL 4 even if the numbers pass.
- The energy budget holds full torque with current during the extended dwell. If the gearbox holds without current, sessions per charge rise.

### Recommended next step

Decide N1 to N5 and name a co-design partner (O1). If Amish accepts N2 to N4, a further TRL 3 pass would add the fingertip thimble and balance pulley to the model and recalculate R3, R7 and R11. TRL 4 is on hold by Amish's instruction. For reference only, TRL 4 would need: a bench build of one finger-pair drive, a finger model with calibrated stiffness, measurements of tendon force against motor current, cuff pressure mapping, breakaway and release tests, and a TST report with `environment: lab`.

## Session 2026-09-25: recommendations accepted

Amish wrote on 2026-09-25: "i accept all your recommendations, go with them across all repos." Every open item with a recommendation (N1 to N5) is now decided as recommended and applied at TRL 3; the co-design partner (O1) has no recommendation and stays open.

### What was done

- `docs/decisions/0002-recommendations-accepted.md` (FXH-DDR-002 v0.1): N1 to N5 recorded as "Decided by Amish, 2026-09-25: go with recommendation", with what changed; O1 left open.
- `docs/decisions/0001-trl2-review-decisions.md` to v0.2: N1 to N5 marked decided.
- `cad/src/model.py`: fingertip thimbles (`thimbles`, BOM 21), four floating balance pulleys (`balance_pulleys`, BOM 22) in channels in an anchor block lengthened from 12 to 44 mm, perforated forearm cuff shell and liner (12 mm holes, 33 % open), flexor sheath route adjusted to the longer block. STEP and STL re-exported, including `flexhand-thimbles.step` and `.stl`.
- `cad/src/sheets.py` and `cad/drawings/FXH-DWG-001.*`: Rev P1 to P2 (balance pulleys, anchor block length, perforation, thimble widths, parts list item 22).
- `docs/04-calcs/sizing.py` and `docs/04-calcs/01-sizing.md` (FXH-CAL-001 v0.1 to v0.2): balance pulley loss and per-finger limit, stop beads, thimble load sharing, new masses, R2 and R5 restated; all tables recomputed.
- `bom/bom.csv`: lines 1 and 10 updated, lines 21 and 22 added; `bom/bom-notes.md` updated.
- `docs/01-problem.md` (v0.4), `docs/02-concept.md` (v0.4), `docs/03-requirements.md` (v0.4) updated; `project.yaml` trl_evidence lists DDR-002; budget, pitch and problem lines unchanged.
- `README.md`: concept paragraph and key components updated; new sections "Concept rationale", "Burning platform", "Where it could be used" and "What sparked the idea" (continuous passive motion, Salter, Toronto, 1978).
- All media regenerated from the model (`cad/src/concept_media.py`), checked by eye; all PDFs re-rendered with the designmolecule.com footer.

### Decisions applied (before and after)

| Item | Change | Before | After |
| --- | --- | --- | --- |
| N1 | R2 wording | "moderate flexor tone" | "mild flexor tone (MAS 1 to 1+)"; 30 N covers the 18 N needed |
| N2 | Fingertip thimbles | Cuff pressure 46 to 84 kPa (96 kPa small hand) | 23 to 40 kPa (46 kPa small hand); hand side 103 to 115 g |
| N3 | Balance pulleys | One finger up to 80 N at the pair trip | 40 N per finger; efficiency 0.694 to 0.659; peak torque 0.467 to 0.492 N·m |
| N4 | Ball-detent couplings, perforated cuff | Pack 675 g | Pack 639 g (40 g and 25 g saved, about 32 g added by the longer block and pulleys) |
| N5 | R5 lower limit | 3 to 15 s | 4 to 15 s at design load; fastest 3.3 s (3.9 s pessimistic) |
| Budget | No change recommended | $500; parts $281.90 | $500; parts $289.90 |

### Requirement status (FXH-CAL-001 v0.2), not met first

| ID | Status | Value against target |
| --- | --- | --- |
| R7 | **Not met** | Pack 639 g against 450 g; hand 115 g against 120 g (met) |
| R2 | At risk | 0.492 N·m peak, 125 % of the gearbox's continuous rating (RMS 68 %) |
| R3 | At risk | 40 N per finger with balance pulleys; friction spread 27 to 47 N at a 40 N setting |
| R1, R4, R5, R6, R10, R11, R12 | Met | 29.8 mm stroke; 445 cycles per hour (360 at 4 s strokes); 3.3 s fastest stroke; 3.8 sessions; three sizes; 40 kPa worst (on paper); $289.90 |
| R8, R9, R13 | Not verifiable at TRL 3 | Donning time; release time; limit lock |

Counts: 7 met, 2 at risk, 1 not met, 3 not verifiable at TRL 3 (was 5, 3, 2, 3).

### Still awaiting Amish

- O1: first clinical co-design partner (no recommendation). The therapist review of the 450 g pack target (D1, N4 (c)) and of the 50 kPa pressure limit waits on it.

### Cross-repo actions

- None. FlexHand does not share parts or interfaces with another repo.

### Safety concerns

- Not a medical device; every document still says so.
- R11 is met only on paper, under an assumed load split between cuff and thimble, and R3 is at risk. Nothing may be worn until pressure is mapped and the force limit is checked on a bench.
- New hazard from N3: with a balance pulley, a free finger can travel up to twice its range if its partner is held back. The stop bead on each finger tendon must be set to that finger's range before any use.
- The gearboxes hold position when unpowered: the tool-free release lever and a care partner within reach remain essential. Protected 2S lithium-ion pack: no charging while worn.

### TRL 4

TRL 4 remains on hold by Amish's instruction. No build, test, purchasing, PCB or firmware work was done. For reference only, TRL 4 would need a bench build of one finger-pair drive with its balance pulley, pressure mapping under cuff and thimble, breakaway, stop-bead and release tests, and a TST report.

### Recommended next step

Name a clinical co-design partner (O1) so that the pack-mass target and the pressure limit can be reviewed with a therapist. The design is otherwise complete at TRL 3.

## Session 2026-09-26: sources strengthened

Amish asked for the weaker sources to be fixed. README sections "Concept rationale" to "What sparked the idea" were checked link by link; every link now in those sections was fetched and supports its claim.

| Where | Old source | New source |
| --- | --- | --- |
| By country or region, India | None (income group and urban concentration of the workforce uncited) | Handa et al., *Current Physical Medicine and Rehabilitation Reports*, 2023 (WHO STARS review): stroke units clustered in metropolitan cities and tertiary centers, nearly absent at primary and secondary facilities |
| By country or region, Brazil | None (public system, ageing population and university groups uncited) | Silva et al., *Arquivos de Neuro-Psiquiatria*, 2024 (2019 National Health Survey): 24.6 % reported access to rehabilitation; 73.4 % of those with activity limitations had no physiotherapy |
| By country or region, Canada | Canadian Medical Hall of Fame (kept) | Same source; the uncited claim about rural distances was removed so the row states only what the source supports |
| Burning platform, therapy dose | Lang et al., 2009 (journal page, kept) | Added the open copy at Marquette University's repository, which was fetched and confirms 312 sessions and 32 repetitions; "hundreds" made specific as 400 to 600 repetitions per session in animal studies |
| Burning platform, dexterity at six months | Kwakkel et al., *Stroke*, 2003 | Removed from the README: the journal and PubMed pages refused automated access in this session, so the 38 % figure could not be re-verified. It remains in `docs/01-problem.md` (a peer-reviewed source, not a weak one) and can return to the README once checked. |
| What sparked the idea | Canadian Medical Hall of Fame plus Salter et al., JBJS 1980 (PubMed) | Canadian Medical Hall of Fame (the official laureate page, which confirms 1978, the Hospital for Sick Children and the immobilization reasoning). The PubMed link was dropped because the page could not be read in this session; the uncited line about bedside, single-joint machines was removed. `INSPIRATIONS.md` line updated to match. |

Kept and re-verified: IHME news release on the GBD 2021 stroke analysis in *The Lancet Neurology* (11.9 million new strokes, 93.8 million survivors, 70 % and 86 % rises, more than three-quarters in low- and middle-income countries); WHO rehabilitation fact sheet (fewer than 10 skilled practitioners per million in many low- and middle-income settings); CDC stroke facts (more than 795,000 strokes a year; a leading cause of serious long-term disability). No budget change; `docs/01-problem.md` cites no weak source for these claims and is unchanged.

## Session 2026-09-26: product appearance model and photoreal renders

Amish chose this repo for the first batch of product renders on 2026-09-26. This session added an appearance model for photoreal renders; the render images themselves (`media/render-hero.png`, `media/render-exploded.png`) are produced separately from it.

### What was done

- `cad/src/product_model.py` (new): `product_parts()` returns 50 parts (49 device parts in the shell and internal groups plus the shared clay forearm and hand as context), with `TITLE` and three `RENDER_VIEWS` (hero, exploded and a thumb-side detail view). It imports `PARAMS`, `derived()` and `build_parts()` from `model.py`; `model.py`, the BOM and the other documents are unchanged. It adds:
  - a motor pack with filleted corners, a parting line between base and lid, four lid screws, side grip ribs, a USB-C port at the charger and a raised "FLEXHAND" marking with a teal accent line;
  - a clear window in the lid over the spools, so the spools, tendon windings and idlers show from outside;
  - an emergency stop with a yellow collar and knurled red mushroom cap, a teal start and pause button and a lit status LED;
  - a filleted anchor block with a seam, hinge lugs and a ribbed teal quick-release lever, with the balance pulleys inside;
  - gearmotors split into encoder cap, can and gearbox; two-flange spools with tendon windings; idler and balance bearings with shields; tendon runs from the spools around the idlers to the exit slots; cells with end caps; circuit boards on an electronics tray;
  - a perforated forearm cuff with a foam liner, hook-and-loop straps (fabric), buckles and teal pull tabs;
  - swept Bowden sheaths with metal ferrules at both ends and sheath stops on the plates;
  - a knit fingerless glove (fabric) with a wrist hem and knuckle binding, TPU dorsal and palmar plates, padded finger cuffs with liners and tendon eyelets, fingertip thimbles with tip tabs, a thumb spacer and the tendons along the fingers.
- `README.md`: hero image now points to `media/render-hero.png`; the links line starts with the exploded render.

Every part is a valid solid and tessellates at the render tolerance. Previews from the kit renderer (without the clear window) were checked for fit on the clay hand.

### Differences from model.py (Proposed, awaiting Amish)

1. **Forearm cuff section.** `model.py` models the forearm as a round cone (radius 29 to 38 mm), while the shared clay forearm is elliptical and flatter. In the appearance model the cuff shell, liner and straps follow the clay forearm with the `model.py` thicknesses (4 mm liner, 2 mm shell), axial extent, hole pattern and strap positions; the pack saddle ribs are trimmed to meet it. Recommendation: keep `model.py` as is for sizing (the round cone is a conservative envelope) and consider an elliptical forearm section when the cuff is fitted at a later TRL.
2. **Hand-side soft parts on the clay hand.** `model.py` puts the finger cuffs, thimbles and tendons on straight fingers along X and the glove and plates on a box palm. Here they sit on the clay hand's relaxed, slightly curled fingers and rounded palm. Cuff and thimble widths, wall and liner thicknesses, the plate plan sizes and the sheath end positions in plan are as `model.py`; the heights of the sheath ends follow the clay palm surface (within about 4 mm). Recommendation: accept for renders only; no change to `model.py`.
3. **Features that are not in the BOM.** The clear spool window, the start and pause button, the status LED light pipe and the "FLEXHAND" marking are appearance proposals. The precis mentions user buttons and the BOM mentions an LED window in the lid, but neither defines them. Recommendation: keep the LED window and one start and pause button; decide on the clear spool window with the enclosure design, since it shows tendon wear but adds a part.
4. **Strap routing.** In `model.py` the straps sit under the cuff liner; here they pass over the cuff shell on top and on the skin underneath, which is how a hook-and-loop strap would hold a half shell. Recommendation: adopt this routing in the concept description when the cuff is next revised.

### TRL

This is an appearance model only: no tolerances, fabrication detail, PCB layouts or build information. `trl` stays 3, and TRL 4 remains on hold by Amish's instruction.

## Session 2026-09-27: kit 1.5.0 and image quality

- Kit 1.5.0 synced: STANDARDS v1.5 (sections 12 to 15: product renders, storefront images and image quality, public release, authorship and signing), `.kit/cards.py`, `.kit/image_qc.py`, `.kit/release_gate.py`, issue templates, and the `/render-product` and `/release` commands. `CLAUDE.md` now matches `.kit/CLAUDE.md`.
- Every `media/render-*.png` recaptioned from its original render with the new layout: the title, concept label and repository sit in a band above the render and the view note in a band below it, each line wrapped to the image width, so no text overlaps other text or the render or runs off the image. `media/card.png` and `media/social-preview.png` regenerated with the same rules.
- `python .kit/image_qc.py` and `python .kit/release_gate.py` pass. trl stays 3.

## Session 2026-10-01: design for construction and prototype build plan (kit 1.7.0)

Amish approved the build plan format on 2026-09-30 and asked for it to be extended to every repo, with outstanding decisions kept in a separate design decisions register. This session installed kit 1.7.0, made the FlexHand design constructable under his 2026-09-30 instruction ("If you are realising that the design cannot be built as per concept - fix the design assumptions to match and be physically feasible as you draw the illustrations."), and wrote the illustrated build plan. Nothing was built or tested; TRL 4 stays on hold.

### What was done

- Kit 1.7.0 installed (`.kit/`, `.claude/commands/`); `CLAUDE.md` matches `.kit/CLAUDE.md`.
- `cad/src/model.py` rewritten as a constructable model, part by part, with `python cad/src/model.py --check`: 203 constructability checks (no overlaps, nothing inside the forearm or hand, every joint touching, clearances, the release plate's path). All pass. STEP and STL re-exported.
- `docs/decisions/0003-design-for-construction.md` (FXH-DDR-003 v0.1, Draft): every change, with its reason; open for Amish's review.
- `cad/src/build_plan_media.py`: overview, 16 making sketches (`cad/drawings/FXH-DWG-101` to `116`), 10 joint close-ups, 15 assembly step pictures and a block-level wiring picture in `docs/05-build-plan/`.
- `docs/05-build-plan.md` (FXH-BLD-001 v0.1) and `docs/06-design-decisions.md` (FXH-DEC-001 v0.1), both new.
- `docs/04-calcs/sizing.py` and `01-sizing.md` (FXH-CAL-001 v0.3): masses recomputed from the new parts; cost reported against the value-engineering target. `docs/02-concept.md` (v0.5), `docs/03-requirements.md` (v0.5) and `docs/01-problem.md` (v0.5) updated to match.
- `bom/bom.csv`: lines 1, 2, 4, 5, 8 to 11, 13 to 15, 17, 19 and 20 updated; lines 23 (electronics tray), 24 (fixing kit) and 25 (5 V regulator) added. `bom/bom-notes.md` updated.
- `cad/src/sheets.py` and `cad/drawings/FXH-DWG-001`: Rev P3. Concept media regenerated with `cad/src/concept_media.py`.
- `project.yaml`: `design_state: constructable`; the build plan, the register and FXH-DDR-003 added to `trl_evidence`; `budget_usd` unchanged. `README.md`: links line and a "Building the prototype" section.

### Design changes made for construction (FXH-DDR-003)

1. Pack screwed to the cuff: floor raised 4 mm; three ribs on the solid strips between cuff holes, six M3 screws up through the shell into heat-set inserts; liner holes over the screw heads.
2. Straps over the shell and through the gap under the pack between its ribs (they were inside the liner).
3. Gearmotors held by a printed 3 mm bulkhead (two M3 screws into each gearbox face) and a cradle with cable ties; motor axes 13.5 mm from centre (was 15).
4. Spool flanges 14 mm (were 20, which the idlers cut into), a set-screw hub; idlers on 3 mm pins in a printed floor post and wall shelf.
5. Rear bay: cells in saddles, an electronics tray on four posts holding them down, boards laid out without overlap, a USB-C opening, a 6 mm cable gap behind the motors, and a 5 V regulator for the controller (a missing part).
6. Anchor block 53 mm long (was 44), 88 mm wide, full pack height, with four 15 by 7 mm channels in line with the tendon exits, holding each line's slack spring, balance pulley (30 mm travel) and two couplings; screwed to the pack front wall.
7. Tool-free release made real: sheath pucks press on a red pull-out release plate between the block and a cover; pulling it out slackens all eight tendons (the lever had no mechanism).
8. Pack 168 mm long, moved 16 to 24 mm toward the elbow; cuff moved 20 mm, same length; the block stops 7 mm short of the wrist.
9. Four slack springs (one per spool line) instead of eight; stop beads at the hand end, against the stop blocks.
10. Finger cuffs and thimbles as padded saddles with thin side bands, eyelets, end tabs and a hook-and-loop closure; fingers held slightly spread by the glove so neighbouring cuffs clear.
11. Sheath stop blocks on the dorsal and palmar plates; plates stitched to the glove; sheaths re-routed so none passes through the wrist, the glove or another sheath.
12. Thumb spacer block moved to the web space, shaped to the thumb and stitched to the glove; glove given a thumb opening.
13. Fixing kit listed (BOM line 24).
14. Breakaway coupling detent: two 2 mm balls and a spring-wire ring in a 6.8 mm body (a 4 mm ball and spring could not fit two couplings side by side).

### Key results (FXH-CAL-001 v0.3)

- Forearm pack about 723 g (was 639 g): **R7 still not met**, now further from 450 g. Hand side 117 g (met).
- Value-engineering target: USD 500. Estimated cost of the constructable design: USD 303.90 (USD 196.10 under the target).
- Forces, speeds, energy, pressures and requirement counts unchanged: 1 not met (R7), 2 at risk (R2, R3), 7 met, 3 not verifiable at TRL 3.

### Proposed, awaiting Amish

Listed in `docs/06-design-decisions.md`: accept the design-for-construction changes; confirm the pull-out release plate in place of the lever; confirm with a therapist that the glove may hold the fingers slightly spread; the pack-mass target (723 g against 450 g); the clinical co-design partner (O1). Eight items to confirm when parts are bought are listed there too.

### Safety

- The release changed form (pull-out plate instead of a lever); its pull force and 10 s release time are TRL 4 bench checks, and it is listed for Amish's confirmation.
- The build plan's safety stops keep everything on a bench and a hand form; nothing may be worn.
- Not a medical device; every document still says so.

### Stale media (made on Amish's Mac)

`media/render-hero.png`, `media/render-exploded.png`, `media/render-detail.png`, `media/card.png` and `media/social-preview.png` still show the concept's pack, anchor block, lever and full-ring cuffs; `cad/src/product_model.py` follows the concept too. They need regenerating on the Mac.

### Kit problems found

- build123d's SVG exporter, used by `.kit/drawing.py`, raises an AssertionError on a projected elliptical arc whose ends coincide (here on the swept sheaths). `.kit/` was not edited; `cad/src/svg_patch.py` skips such arcs, as build123d already does for arcs shorter than 1e-6, and is imported by `sheets.py`, `concept_media.py` and `build_plan_media.py`. The kit should carry the fix.
- The mirrored constructable pack base raised a Standard_DomainError in hidden-line projection, so the concept media and FXH-DWG-001 now show the right-hand device as modelled (the media were a mirrored left hand before), matching the build plan.

### Recommended next step

Review FXH-DDR-003 and the register (items 2 to 5). TRL 4 remains on hold.

## Session 2026-10-02: open-decision recommendations approved

Amish, 2026-10-02: "i approve your recommendations for all 555 open decisions." This approves the recommendation for every open decision in the design decisions register. 5 decisions were recorded: each moved to Decisions made, dated 2026-10-02, with the approved recommendation and its record. trl stays 3; no build or test work was done, and the CAD model, BOM quantities and prices, and pictures were not changed.

### Documents changed

- `docs/06-design-decisions.md` (FXH-DEC-001 v0.2): the five open decisions moved to Decisions made; Open decisions now reads none; value engineering states that the listed mass savings cannot close the R7 gap
- `docs/decisions/0003-design-for-construction.md` (FXH-DDR-003 v0.2): status accepted with Amish's words; A1 to A3 accepted with their conditions (release pass mark, no wearing before the spread check, pack mass as a safety question)
- `docs/decisions/0001-trl2-review-decisions.md` (FXH-DDR-001 v0.3): O1 (first clinical co-design partner) decided
- `docs/decisions/0002-recommendations-accepted.md` (FXH-DDR-002 v0.2): O1 decided
- `docs/03-requirements.md` (FXH-REQ-001 v0.6): R9 release pull force agreed with the therapist before the test; R7 pack target reviewed as a safety question; safety note adds the spread check; no status changed
- `docs/04-calcs/01-sizing.md` (FXH-CAL-001 v0.4): R9 target wording in the requirement table; no result changed
- `docs/02-concept.md` (FXH-PRC-001 v0.6): safety section adds the release pass mark, the finger spread check and the pack mass; partner named; design for construction accepted
- `docs/01-problem.md` (FXH-PRB-001 v0.6): open question on the first clinical partner answered
- `docs/05-build-plan.md` (FXH-BLD-001 v0.2): release check pass mark and safety stop S6 carry the safety conditions; no open decision added
- PDFs regenerated with `python3 .kit/render.py`; superseded PDF versions removed by the render.

### Follow-up actions to carry approved decisions into the design

1. Decision 2 (pictures): Regenerate the photoreal renders, `media/card.png` and `media/social-preview.png` from `cad/src/product_model.py` to show the accepted construction (screwed pack, anchor block, release plate, saddle cuffs), on Amish's Mac
2. Decision 5 (model): Try the listed mass savings in the model before TRL 4: plastic or aluminium screws for the lid, tray and cover, lower infill and thinner ribs in the pack base, and a lighter anchor block
3. Decision 5 (calcs): Re-run `sizing.py` and update FXH-CAL-001 section G with the result of the savings tried; R7 stays not met unless the therapist review changes the target
4. Decision 5 (bom): Update `bom/bom.csv` for any fixings changed by the savings (plastic or aluminium screws)

### Points found in the review

- The value-engineering savings for mass (about 8 g of screws, 10 to 20 g of infill, a lighter anchor block) cannot close a 273 g gap to R7; the register should say so plainly.
- Kit bug noted in the review: build123d's SVG export fails on closed elliptical arcs; the local svg_patch workaround should move into the kit.

## Approved follow-ups carried out (2026-10-02)

Amish approved all follow-up actions from the open-decision sign-off on 2026-10-02. Results for FlexHand (research and educational prototype, not a medical device):

1. Decision 5, model: done. Three of the listed mass savings were tried in `cad/src/model.py`: saddle ribs in the pack base thinned from 4 to 3 mm (2.6 g), a larger lightening pocket in the anchor block (3.4 g), and aluminium M3 screws for the lid and the cover (5.4 g, in the calculation). Not done: aluminium or plastic screws for the electronics tray, because aluminium screws are not made in the M2.2 self-tapping size; lower infill in the pack base, because it is a print setting that saves little in 2 mm walls and is left to the TRL 4 prints. All 203 constructability checks pass. STEP and STL regenerated.
2. Decision 5, calculations: done. `docs/04-calcs/sizing.py` re-run: pack 723 g to 712 g (11.4 g saved), still 262 g over the 450 g target. R7 stays not met; only the therapist review of the target can change that. FXH-CAL-001 section G records the savings tried (G6).
3. Decision 5, BOM: done. Line 24 (fixing kit) now lists aluminium M3 screws for the lid (four M3 x 8) and the cover (four M3 x 16), USD 10 to USD 11. Basis: about USD 0.20 each from fastener retailers against about USD 0.05 for steel. Cost USD 303.90 to USD 304.90.
4. Decision 2, pictures: done as far as it can be here. `cad/src/product_model.py` was rebuilt from the constructable model: three saddle ribs from the model, lid screws over the lid bosses, the anchor block at 88 mm wide with four channels and its pocket, the red pull-out release plate with finger loop, the sheath pucks, the cover with four screws, sheaths starting at the cover on the model's line heights, and saddle finger cuffs and thimbles with thin side bands. The old quick-release lever is gone. Render scenes exported to `/home/claude/renders/flexhand`. The photoreal renders, `media/card.png` and `media/social-preview.png` are made on Amish's Mac next.

Requirement status changes: none (R7 not met at 712 g; R12 under the target by USD 195.10).

Documents changed: FXH-CAL-001 v0.5, FXH-PRC-001 v0.7, FXH-REQ-001 v0.7, FXH-BLD-001 v0.3 (aluminium lid and cover screws snug only, 712 g), FXH-DEC-001 v0.3 (value engineering section), `README.md`. Drawings: FXH-DWG-001 now Rev P4; FXH-DWG-101 and 102 and the concept sheet regenerated.

### Points for Amish

- The appearance model's forearm cuff shell reports an invalid solid in `product_model.py`; it was so before this session and renders from the exported scene.

## 2026-10-02: photoreal renders redone on the constructable design

Rendered with Blender Cycles on Amish's Mac from the updated appearance model; captioned with `.kit/photo_caption.py`; `media/card.png` and `media/social-preview.png` regenerated with `.kit/cards.py`. Views: hero, exploded, detail. image_qc passes. Appearance deviations are those logged above as proposed, awaiting Amish.

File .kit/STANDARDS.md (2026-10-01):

---
doc_id: OHP-STD-001
title: Documentation and drawing standard
project: Open Hardware Portfolio
doc_type: Standard
version: "1.7"
status: Released
date: 2026-09-30
author: Amish Chadha
license: CC-BY-SA-4.0
revisions:
  - version: "1.0"
    date: 2026-09-24
    author: Amish Chadha
    change: First release of the standard
  - version: "1.1"
    date: 2026-09-24
    author: Amish Chadha
    change: Adopt Technology Readiness Levels (section 9) for project maturity
  - version: "1.2"
    date: 2026-09-24
    author: Amish Chadha
    change: Portfolio phase cap (section 10), concept media standard (section 11), CLAUDE.md guardrails
  - version: "1.3"
    date: 2026-09-24
    author: Amish Chadha
    change: Scale figure, interactive 3D viewer and flow diagrams added to concept media; session slash commands
  - version: "1.4"
    date: 2026-09-26
    author: Amish Chadha
    change: Every sheet and render names the project and its GitHub repository; overall dimensions, ISO centre lines and 300 dpi PNG on sheets; titles name the device and view labels state the viewing direction; optional photoreal renders with Blender
  - version: "1.5"
    date: 2026-09-27
    author: Amish Chadha
    change: Product renders (section 12), storefront images and image quality check (section 13), public release and release gate (section 14), authorship, citation and commit signing (section 15)
  - version: "1.6"
    date: 2026-09-29
    author: Amish Chadha
    change: Licensing metadata with REUSE (section 16), Zenodo DOI and Software Heritage archiving (section 17), release gate checks REUSE and a single CITATION.cff license, archive.py
  - version: "1.7"
    date: 2026-09-30
    author: Amish Chadha
    change: Concept and constructable design states; design decisions register (DEC) kept apart from the build plan; prototype build plan (BLD, section 18) with pictures by component is required TRL 3 evidence; every repo targets TRL 3 during the populate phase; build_views.py; /to-trl3 and /build-plan commands
---

# Documentation and drawing standard

Every project in the portfolio uses this standard, so that each precis, write-up and sketch looks the same and carries its own version history. The standard ships as a kit in each repo's `.kit/` folder. The kit version is in `.kit/KIT_VERSION`.

## 1. Document types and IDs

Every controlled document has a unique ID in the form `PRJ-TYP-NNN`.

- `PRJ` is the three-letter project code listed in section 7.
- `TYP` is the document type code from the table below.
- `NNN` is a sequence number within that project and type, starting at 001.

| Code | Type | Typical file |
| --- | --- | --- |
| PRC | Design precis | `docs/02-concept.md` |
| PRB | Problem statement | `docs/01-problem.md` |
| REQ | Requirements | `docs/03-requirements.md` |
| CAL | Calculation or sizing note | `docs/04-calcs/*.md` |
| DDR | Design decision record | `docs/decisions/*.md` |
| BOM | Bill of materials | `bom/bom.csv` |
| DWG | Drawing or sketch sheet | `cad/drawings/*.svg` |
| BLD | Prototype build plan (section 18) | `docs/05-build-plan.md` |
| DEC | Design decisions register (section 18) | `docs/06-design-decisions.md` |
| TST | Test plan or test report (front matter adds `environment: lab` or `relevant`) | `docs/05-tests/*.md` |

Example: `TBK-PRC-001` is the ThermaBrick design precis.

## 2. Revision scheme

| Artifact | While in draft | When released | Change after release |
| --- | --- | --- | --- |
| Documents | 0.1, 0.2, 0.3 ... | 1.0 | 1.1 for minor edits, 2.0 for a design change |
| Drawings | Rev P1, P2 ... (preliminary) | Rev A | Rev B, C ... |

- Every change to a controlled document adds a row to its revision history before the commit.
- The `version` field in front matter always equals the newest row in `revisions`. The renderer rejects a document where they differ.
- Status is one of `Draft`, `In review`, `Released` or `Superseded`. Draft and In review documents print with a status band on every page.
- Every release is tagged in Git as `<doc_id>/v<version>`, for example `TBK-PRC-001/v1.0`. Drawings are tagged `TBK-DWG-001/revA`.
- Git history is the full audit trail. The in-document revision table is the human-readable summary.

## 3. Document front matter

Every Markdown document under version control starts with this block:

```yaml
---
doc_id: TBK-PRC-001
title: ThermaBrick design precis
project: ThermaBrick
doc_type: Precis
version: "0.1"
status: Draft
date: 2026-09-24
author: Amish Chadha
license: CERN-OHL-S-2.0
revisions:
  - version: "0.1"
    date: 2026-09-24
    author: Amish Chadha
    change: Initial draft
---
```

Quote version numbers so YAML keeps `1.0` as text instead of turning it into a number. List revisions newest last.

## 4. Writing style

- Chicago Manual of Style.
- No em dashes. Restructure the sentence instead.
- Lead each section with its conclusion, then support it.
- SI units throughout, in the form `12 kW`, `450 °C`, `3.2 m`. Imperial values may follow in parentheses.
- Number every figure and table ("Figure 2", "Table 1") and give each a caption.
- State every assumption in the calculation that depends on it.
- Put safety notes in a blockquote starting with **Safety:**.

## 5. Visual identity

| Element | Specification |
| --- | --- |
| Typeface | IBM Plex Sans for text, IBM Plex Mono for code and values (SIL Open Font License, bundled in `.kit/fonts`) |
| Ink | `#111827` |
| Secondary text | `#4B5563` |
| Rules and grid | `#D1D5DB` |
| Accent (one only) | `#0F766E` teal |
| Document page | US Letter, 20 mm margins |
| Drawing sheet | ANSI B landscape (431.8 x 279.4 mm) |
| Footer | Document ID, version, status, license and designmolecule.com on every page |

## 6. Drawing and sketch conventions

- Units are millimeters unless the title block says otherwise.
- Third-angle projection, marked with the symbol in the title block.
- Line weights: visible outlines 0.5 mm, hidden lines 0.25 mm dashed, center lines 0.18 mm chain.
- The title block contains the project, title, drawing number, revision, scale, units, projection, sheet, author, date, material or notes, and license.
- Every sheet and every render names the project and its GitHub repository (from `repo:` in `project.yaml`), at the top of the sheet and in the title block, so a printed or forwarded sheet is never anonymous.
- The drawing title names the device, not only the drawing type (for example "Handheld near-infrared resin scanner: general arrangement").
- Every view label states its scale and viewing direction (for example "Scale 1:1; side elevation looking along +Y"), and every isometric or render states where it is seen from.
- Orthographic views generated with `add_ortho` carry overall dimensions (length and depth on the top view, height on the front view) and ISO 128 centre lines on cylinders; hidden lines are dashed. Tolerances are not shown before TRL 4.
- Sheets are exported as SVG, PDF and a 300 dpi PNG.
- The revision table in the top right of the sheet lists every revision.
- Concept sketches use the same sheet and title block and carry the label "CONCEPT, NOT FOR FABRICATION".
- Geometry comes from `cad/src/*.py` (build123d). Sheets are generated by `.kit/drawing.py` and never edited by hand.

## 7. Project codes

| Code | Project | Code | Project | Code | Project |
| --- | --- | --- | --- | --- | --- |
| TBK | ThermaBrick | PCF | PicoFlow | HLT | HelioLite |
| CCB | CharCube | DRN | DustRunner | TRT | TremorTrace |
| STC | StepCue | FXH | FlexHand | CPD | ColdPod |
| SCL | SunClave | STR | SteamRoot | GGD | GrainGuard |
| SDL | SeedLine | ZBX | ZeerBox | RMS | RootMesh |
| DWD | DewDrive | SSK | StillStack | PPR | PotPress |
| WWT | WaterWatch | LMF | LumaFlow | FCL | FieldCell |
| CNP | ConePro | CVC | CulvertCrawl | EGD | EmberGuard |
| SNF | SnapFrame | CGM | CargoMule | SCM | StepClimber |
| SWC | SwapCell | PLP | PalletPilot | FTK | FlatTrike |
| WWK | WaterWalker | GRR | GrowRider | SSP | SunSpoke |
| SGN | StepGen | PBX | PowerBox | WML | WasteWise-ml |
| WSC | WasteWise Scan | RFE | ReflowEconomy | | |
| OHP | Portfolio-wide | | | | |

## 8. Build and publish

- `python .kit/render.py` checks every controlled document and renders it to `docs/pdf/<doc_id>_v<version>.pdf`.
- `python .kit/drawing.py` (called from each project's `cad/src/sheets.py`) builds drawing sheets as SVG and PDF in `cad/drawings/`.
- The GitHub Action in `.github/workflows/docs.yml` runs the checks on every push and attaches PDFs to a GitHub Release whenever a release tag is pushed.
- Public releases follow section 14: `python .kit/release_gate.py` must pass, and the release tag is `v0.<TRL>.0` (for example `v0.3.0` at TRL 3).

## 9. Technology Readiness Level (TRL)

Each project states its maturity as a Technology Readiness Level on the NASA and US DOE 1 to 9 scale. The TRL rates this specific design, not the underlying technology. A sand battery is commercial elsewhere, but a new sand battery design starts at TRL 2 until evidence shows otherwise.

| TRL | Definition | Evidence the repo must contain |
| --- | --- | --- |
| 1 | Basic principles observed | Problem statement (PRB) |
| 2 | Technology concept formulated | Draft precis (PRC) and requirements (REQ) |
| 3 | Analytical or experimental proof of concept | Calculation note (CAL), working build123d model with STEP export, drawing sheet (DWG), priced BOM with every unit cost filled in, prototype build plan (BLD) with pictures, `design_state: constructable` |
| 4 | Components validated in the lab | Test report (TST) with `environment: lab`, build log entries |
| 5 | Validated in a relevant environment | Test report (TST) with `environment: relevant` |
| 6 | System prototype demonstrated in a relevant environment | Precis at version 1.0 or later with status Released, a drawing at a lettered revision (Rev A or later), and a system-level TST with `environment: relevant` |
| 7 to 9 | Operational demonstration through proven in service | Beyond portfolio scope; claim only with a named deployment partner and evidence |

Rules:

- `project.yaml` records `trl` (current level), `trl_target` (the level the current effort aims for) and `trl_evidence` (the files that support the claim).
- `python .kit/render.py --check` fails if the evidence for the claimed TRL is missing. CI runs this check on every push.
- Documentation alone cannot go past TRL 3. TRL 4 and above require hardware and a test report.
- TRL and visibility are independent. A repo can be public at TRL 3 as a documented design ready to build.
- A change of TRL is recorded in the build log with the date and the evidence that justified it.

## 10. Portfolio phase and TRL cap

`.kit/PHASE.yaml` sets the current phase. During the **populate** phase every repo is capped at **TRL 3**: `trl` and `trl_target` may not exceed 3, and the check fails if they do. Every repo targets the cap: `trl_target` must equal 3, so a new repo is taken all the way to TRL 3 (scaffold, populate and advance, see `/to-trl3`). Work that belongs to TRL 4 or later (building or testing hardware, test articles, test plans and reports, build-log entries, purchasing lists, PCB layouts) must not be started. The prototype build plan (BLD, section 18) is TRL 3 paper work and is required. Where it already exists it is kept, flagged in the check output, and not extended. Only Amish changes `PHASE.yaml`.

Every repo carries a `CLAUDE.md` with the working rules for AI sessions: the TRL cap, decision rights (nothing is recorded as decided unless Amish decided it), one step per session, and a mandatory `docs/REVIEW.md` before stopping.

## 11. Concept media

Every repo at TRL 2 or above explains its idea visually. Media are generated from a build123d massing model with `.kit/concept.py`, never drawn by hand, so they stay in step with the design.

| File | Required | Purpose |
| --- | --- | --- |
| `media/hero.png` | TRL 2+ | Shaded isometric render with a 1.75 m person for scale; the website card image |
| `media/concept-blueprint.png` and `.pdf` | TRL 2+ | Blueprint concept sheet: orthographic and isometric views, scale, key figures, title block |
| `media/model.glb` and `media/viewer.html` | TRL 2+ | Interactive 3D viewer (glTF plus model-viewer) for the website |
| `media/cutaway.png` | When the inside matters | Section view showing internal parts |
| `media/exploded.png` | Recommended | Exploded view with numbered callouts matching the BOM |
| `media/flow.png` | When energy or material moves | System, energy or material flow diagram with losses |

Session commands in `.claude/commands/` (`/populate`, `/advance-trl3`, `/rein-in`, `/refresh-media`) carry the standard prompts, so every Claude Code session starts from the same instructions.

At TRL 2 a massing model is enough: correct overall proportions and main components. All concept media carry "CONCEPT, NOT FOR FABRICATION". The check warns when required media are missing at TRL 2 and fails at TRL 3.

## 12. Product renders

Every repo at TRL 3 shows the product as it would look, not only as a massing model.

- `cad/src/product_model.py` is the appearance model. It defines `product_parts()` (named parts with a shape and a material), `TITLE` ("Name: what it is") and `RENDER_VIEWS`. It is for renders only: every main dimension comes from `cad/src/model.py`, never typed in again.
- Where the appearance model departs from `model.py` (a chamfer, a label, a fastener drawn for realism), record the deviation in `docs/REVIEW.md` as "Proposed, awaiting Amish".
- Scale comes from context, not from a floating figure: a hand or forearm for handheld objects, and the posed mannequin (`mannequin()` in `.kit/context_parts.py`: stand, walk, push, ride, sit, reach) for anything a person uses at body scale.
- Renders are made with `.kit/export_views.py` (one scene per view) and `.kit/photoreal.py` (Blender Cycles), then captioned with `.kit/photo_caption.py`. Files are `media/render-<view>.png`; `media/render-hero.png` is required.
- Every caption names the project, the repository and the viewing direction, and carries "CONCEPT, NOT FOR FABRICATION".
- Captions never sit on the render. `.kit/photo_caption.py` adds a header band (title, concept label, repository) above the render and a footer band (view note) below it, wraps every line to the image width, and steps the font down to a floor before adding a line.
- The README opens with `media/render-hero.png`.
- Software-only and scene repositories (no single product) may use a scene render as the hero instead of a product model.

## 13. Storefront images

Two images, both made from `media/render-hero.png` by `python .kit/cards.py .`:

| File | Size | Purpose |
| --- | --- | --- |
| `media/card.png` | 800 x 800 | Square thumbnail for the organization profile page |
| `media/social-preview.png` | 1280 x 640, under 1 MB | GitHub social preview, shown when a repository link is shared |

- The social preview shows the area, name, one-line description, the first sentence of the pitch, the brand line and the repository address. Design Molecule repos read "Design Molecule · open hardware concept, TRL n"; OpenRatio repos read "OpenRatio · research and educational prototype, TRL n".
- GitHub has no API for the social preview. Upload it under the repository's Settings, Social preview, on release day.
- Regenerate both images whenever `render-hero.png` changes.

### Image quality

Every render, card and social preview must be clear and readable. `python .kit/image_qc.py` checks each one, and the release gate blocks on any failure:

| Check | Rule |
| --- | --- |
| Layout | Made by the current `photo_caption.py` or `cards.py`, which store the text layout in the PNG |
| Text inside the image | Every line at least 1.2 % of the image width from each edge; nothing runs off the side |
| No overlap | No line of text touches another line, and no caption text sits on the render |
| Text size | Render captions at least 1.05 % of the image width in pixel height (17 px at 1600 px); social preview text at least 16 px |
| Resolution | Renders at least 1200 px wide; card 800 x 800; social preview 1280 x 640 and under 1 MB |
| Sharpness | The render is not blurred or upscaled (edge sharpness at least 15 on the `image_qc.py` scale) |

Long titles and notes wrap to more lines rather than shrinking below the floor. The social preview shortens the pitch sentence with an ellipsis only if it cannot fit at the smallest size.

## 14. Public release

A repository goes public only when Amish approves it, and only after `python .kit/release_gate.py` passes. The gate checks:

1. `render.py --check` passes (document control, TRL cap, concept media).
2. Storefront: hero render, card, social preview under 1 MB, README leading with the hero, and every image passing the image quality check (section 13).
3. Issue templates in `.github/ISSUE_TEMPLATE/`: question, build report, design suggestion. The build report template restates that the design is a TRL 3 concept, not released for fabrication (OpenRatio: a research and educational prototype, not a medical device).
4. `CITATION.cff` valid, with an author ORCID.
5. License files match `project.yaml`.
6. No em dashes in the repository's own text.
7. BioMedical and OpenRatio repos use soft, non-clinical wording: "research and educational prototype, not a medical device".
8. No secrets anywhere in the history (gitleaks).
9. No links to sibling repositories that are still private.
10. REUSE files present (`REUSE.toml`, `LICENSES/`, `.github/workflows/reuse.yml`) and `reuse lint` passes (section 16).
11. `CITATION.cff` names exactly one license, because Zenodo rejects a list (section 17).

It warns, without blocking, when the README lacks a Safety heading or a "not for fabrication" statement, when `CITATION.cff` has no DOI yet, and when the README lacks the Zenodo DOI, REUSE or Software Heritage badge, so a person can confirm.

On release day, per repository:

- A signed, annotated tag `v0.<TRL>.0` on `main`.
- A GitHub release with short notes (what it is, TRL, status, licenses, how to cite) and a design pack, `<repo>-v0.<TRL>.0-design-pack.zip`, holding `cad/step`, `cad/drawings`, `docs/pdf`, `bom`, README, licenses and `CITATION.cff`.
- Description from the first sentences of `pitch` (350 characters at most), website `https://designmolecule.com` (OpenRatio: `https://openratio.ai`), topics from `project.yaml`.
- Before the first release, the repository is switched on in Zenodo (section 17), so the release is archived and gets a DOI.
- Visibility switched to public last, after the release exists.
- The social preview uploaded and the organization profile updated with the new cards.
- After the release: the concept DOI written to `CITATION.cff` and a Software Heritage save requested (section 17).

The internal working files (`CLAUDE.md`, `.kit/CLAUDE.md`, `.claude/commands/`, `docs/REVIEW.md`) stay public, and open "Proposed, awaiting Amish" items stay visible as open questions (Amish, 2026-09-27).

## 15. Authorship, citation and signing

- Amish Chadha is the author of every design, ORCID 0009-0000-8079-7141. Commits are authored as Amish Chadha <amish@designmolecule.com>.
- `CITATION.cff` lists Amish (with ORCID) first, then any credited contributors; `CONTRIBUTORS.md` and the README Credits section agree with it.
- `CITATION.cff` names one license: the hardware license (CERN-OHL-S-2.0), or the software license in a software-only repository. The full split between hardware and software licenses lives in `REUSE.toml` and the README. Once the repository is archived, `CITATION.cff` carries the concept DOI in `doi:`.
- Work done with Claude carries the trailer `Co-Authored-By: Claude <noreply@anthropic.com>` (with the model name), and the README Credits section says designs are developed with AI assistance.
- Every commit and tag pushed to GitHub is signed with Amish's SSH signing key, so GitHub shows it as Verified. Commits prepared elsewhere are re-signed on Amish's Mac before they are pushed.
- Once a repository is public, its history is never rewritten.

## 16. Licensing metadata (REUSE)

Every file states its copyright and license in a machine-readable way, following the REUSE Specification 3.3 (https://reuse.software). A repository is set up with:

```
python .kit/archive.py reuse
```

This writes three things and adds the REUSE and Software Heritage badges to the README badge line:

- `REUSE.toml`, built from the licenses in `project.yaml`. Everything is under the hardware license by default. Scripts, firmware, notebooks, web viewers, workflows and agent commands are under the software license. `cad/` and `electronics/` stay under the hardware license even where they are written as Python. The bundled IBM Plex fonts are OFL-1.1 (IBM Corp.). Copyright is "<first commit year> Amish Chadha".
- `LICENSES/`, with the full text of each license used (`reuse download`). The root `LICENSE` and `LICENSE-SOFTWARE` files stay for GitHub's license detection.
- `.github/workflows/reuse.yml`, which runs the REUSE check (fsfe/reuse-action) on every push and drives the README badge.

A new kind of file that falls outside these rules gets a new annotation in `REUSE.toml` rather than a header comment. `reuse lint` must pass before every commit that adds files, and the release gate enforces it.

## 17. Archiving and DOI (Zenodo and Software Heritage)

Every public repository is archived twice, so the design stays citable and retrievable if GitHub changes.

Zenodo (a citable DOI for each release):

1. Amish's Zenodo account is linked to GitHub. Before the first release, Amish switches the repository on in Zenodo (Account, GitHub). Only Amish changes Zenodo or GitHub settings.
2. Run `python .kit/archive.py zenodo`: it makes sure `CITATION.cff` names one license and adds the Zenodo DOI badge, which uses the GitHub repository ID and always points at the latest version. Zenodo reads its metadata (title, authors with ORCID, license, keywords) from `CITATION.cff`, and rejects the whole archive when that file lists several licenses.
3. Publish the GitHub release (section 14). Zenodo archives it within minutes and mints two DOIs: a version DOI for that release and a concept DOI that stands for all versions.
4. Check the Zenodo record: title, author and ORCID, license, keywords. If Zenodo shows "Citation metadata load failed", fix `CITATION.cff`, validate it with cffconvert and publish a new patch release (for example `v0.3.2`); a failed release is never re-used.
5. Run `python .kit/archive.py zenodo --doi <concept DOI>` and commit, so GitHub's "Cite this repository" and every future archive carry the concept DOI. Every later release gets its own version DOI automatically; the concept DOI never changes.

Software Heritage (permanent source archive):

1. After the repository is public, request a save at https://archive.softwareheritage.org/save/ (origin type git, the repository URL). Anonymous requests are limited to about ten an hour, so batches are spread out.
2. The Software Heritage badge on the README resolves once the save is accepted and ingested. Later pushes are picked up by its regular crawl.

OpenRatio repositories follow the same steps when Amish approves their release.

## 18. Prototype build plan (BLD) and the constructable design

### Two design states

A design moves through two states, recorded as `design_state` in `project.yaml`:

- **Concept**: the design shows what the product does and that it works on paper (TRL 2 and the calculations of TRL 3). Parts may be simplified shapes that have never been checked for how they are made or how they join.
- **Constructable**: every part can be made with the stated process and material, and every part fits and fastens to the parts next to it. Nothing is left as a shape that cannot be cut, cast, bent, printed, machined or bought.

A repo reaches TRL 3 only when its design is constructable and its build plan shows how. Writing the build plan is how the design is made constructable: when a part cannot be made or cannot fit as modelled, change the model so it can (Amish, 2026-09-30: "fix the design assumptions to match and be physically feasible"), keep what the concept does, and record every change in a decision record "Design for construction" (DDR) and in the plan. Changes that alter what the product does, its pitch or its safety case are proposed, not made.

### What the build plan is

`docs/05-build-plan.md` (`PRJ-BLD-001`) tells a capable maker how to build the first proof-of-concept prototype, in order, component by component, and shows it in pictures. It is written before anything is built, states "Plan, not yet built" under the title and never claims results. Building and testing to it is TRL 4 work.

### Writing rules

- **Plain English.** Say "the steel plate the jack stands on", not a model parameter or variable name. No code identifiers, function names, parameter names or file paths in the body of the plan. Give sizes as numbers with units ("a 62 mm hole, centred 100 mm up from the bottom edge"). The only place file names appear is the closing "Where the numbers come from" list.
- **Pictures first.** Every component and every assembly step has a picture. A reader should be able to build from the pictures, with the words explaining what the pictures cannot show (order, force, tolerance, checks).
- **By component, in build order.** Each component is made and checked before the step that needs it.
- **Cost is not the focus.** One line in the overview may state the parts cost from the BOM; there is no cost or time section.
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

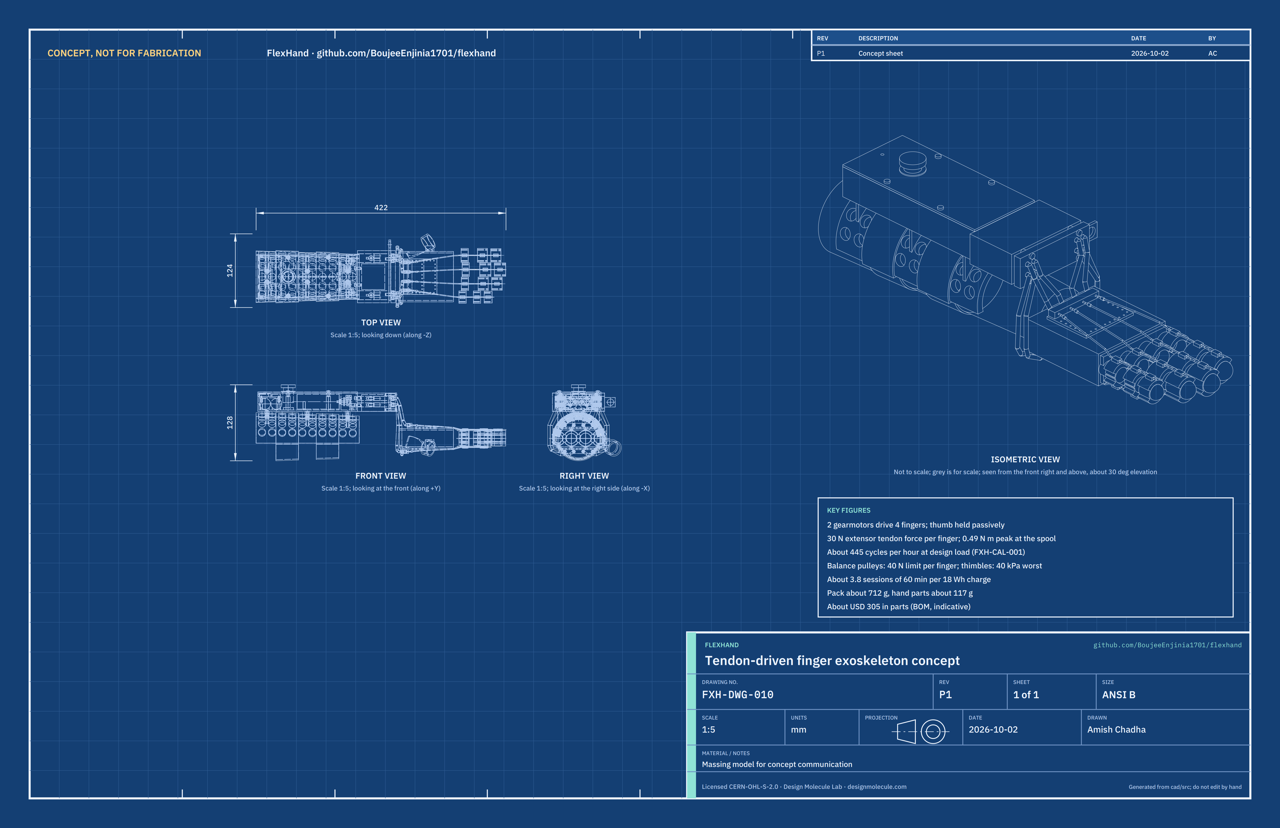
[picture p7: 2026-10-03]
media/concept-blueprint.png

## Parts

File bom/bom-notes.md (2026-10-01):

# BOM notes

- Line numbers match the callouts in `media/exploded.png` and the parts list on drawing FXH-DWG-001 (Rev P3). Line 19 (wiring and consumables) is not modeled.
- Every line is priced. Costs are indicative single-unit prices in USD for TRL 3 review. The gearmotor price (line 3, Pololu 4869, $53.95) was checked with the supplier on 2026-09-25; the other prices are indicative and suppliers are not yet selected.
- Value-engineering target: USD 500 (`budget_usd` in `project.yaml`, a hypothetical control target, not a limit). Estimated cost of the constructable design: USD 303.90 (USD 196.10 under the target), computed by `docs/04-calcs/sizing.py` [J1].
- The gearmotor choice (line 3) was decided by Amish on 2026-09-25 (FXH-DDR-001, D1).
- Lines 1, 10, 21 and 22 changed after Amish accepted the TRL 3 recommendations on 2026-09-25 (FXH-DDR-002): the forearm cuff is perforated (N4), the anchor block is 44 mm long with ball-detent breakaways, balance pulley channels and tendon stop beads (N3, N4), and the fingertip thimbles (line 21, N2) and balance pulley bearings (line 22, N3) are new.
- Line 15: the anchor cuffs are as wide as each middle phalanx allows (12.2 to 18.6 mm). With the thimbles of line 21 sharing the load, contact pressure meets R11 on paper (FXH-CAL-001, section H).
- Line 20 (idler bearings) is new at TRL 3, from the layout with the motors along the forearm.
- This is a priced bill of materials for design review, not a purchasing list.
- FXH-DDR-003 (design for construction, 2026-10-01) changed lines 1, 2, 4, 5, 8 to 11, 13 to 15, 17, 19 and 20 and added line 23 (electronics tray), line 24 (fixing kit) and line 25 (5 V regulator). Line 19 no longer covers fasteners; they are in line 24.

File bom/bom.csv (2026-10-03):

Item | qty | spec | supplier | unit_cost_usd | make_buy | notes
1 Forearm cuff | 1 | 3D-printed PETG half shell 2 mm perforated with 12 mm holes, six 3.4 mm holes for the pack screws; 4 mm EVA foam liner perforated to match, with 6.5 mm holes over the screw heads; two 38 mm hook-and-loop straps that pass under the pack between its ribs | Self (print); strap and foam from online retailer | 10.00 | make | Indicative; material and straps; perforation per FXH-DDR-002 (N4); screw holes and strap path per FXH-DDR-003
2 Pack base | 1 | 3D-printed PETG, 168 x 76 mm, 2 mm walls; three saddle ribs with screw bosses, motor bulkhead and cradle, cell saddles, tray ledges, idler post and shelf, four lid bosses, tendon exit holes, USB-C opening | Self (print) | 6.00 | make | Material cost only; features per FXH-DDR-003
3 Gearmotor with encoder | 2 | 227:1 metal gearmotor 25D x 71L mm MP 12 V, 48 CPR encoder (Pololu 4869), run at 7.2 V | Pololu or distributor | 53.95 | buy | Pololu single-unit price checked 2026-09-25; D1 decided by Amish 2026-09-25
4 Antagonistic spool | 2 | Two-groove spool, 10 mm core, 14 mm flanges, 4 mm hub with M3 set screw, 16 mm long, 4 mm D-bore; printed PA12 | Online print service or self | 4.00 | make | Indicative; flange reduced from 20 mm to clear the idlers (FXH-DDR-003)
5 Li-ion pack 2S | 1 | 2 x 18650 cells, 2,500 mAh each, with 2S protection board; cells sit in saddles in the pack base under the electronics tray | Battery distributor | 22.00 | buy | Indicative; use cells and BMS from a reputable source
6 Controller | 1 | ESP32-S3 module (Seeed XIAO ESP32S3 class) | Seeed Studio or distributor | 8.00 | buy | Indicative
7 Motor driver with current sense | 2 | DRV8874 single H-bridge carrier with current-sense output (Pololu 4035 class) | Pololu or distributor | 10.00 | buy | Indicative
8 Pack lid | 1 | 3D-printed PETG 2 mm with emergency stop opening, LED window and four screw holes | Self (print) | 3.00 | make | Material cost only
9 Emergency stop button | 1 | 16 mm latching mushroom switch with bezel and panel nut, NC contact in the motor supply, 18 mm deep | Electronics distributor | 6.00 | buy | Indicative
10 Sheath anchor block | 1 | Printed block 53 x 88 x 31 mm with four tendon channels; release plate (3 mm, with pull loop) that slides out to free all sheaths; cover with four puck pockets; four sheath pucks; 8 ball-detent breakaway couplings (two 2 mm steel balls and a 0.4 mm spring-wire ring each, 6.8 mm body); 4 slack springs; 8 crimped tendon stop beads | Self (print); balls springs and crimps from online retailer | 18.00 | make | Indicative; ball-detent couplings per FXH-DDR-002 (N4); release plate, pucks and channel layout per FXH-DDR-003; breakaway force to be set at TRL 4
11 Bowden sheath set | 1 | 2 m of 4 mm PTFE-lined shift housing cut to 8 lengths (4 of about 80 mm, 4 of about 145 to 165 mm), 16 ferrules | Bicycle parts retailer | 11.00 | buy | Indicative
12 Base glove | 1 | Fingerless breathable glove, sizes S, M, L | Online retailer | 12.00 | buy | Indicative
13 Dorsal plate | 1 | TPU 95A print, 50 x 60 x 2.5 mm plate with a sheath stop block for the 4 extensor sheaths and stitching holes | Self (print) | 2.00 | make | Material cost only
14 Palmar plate | 1 | TPU 95A print, 34 x 60 x 2.5 mm plate with a sheath stop block for the 4 flexor sheaths and stitching holes | Self (print) | 2.00 | make | Material cost only
15 Finger cuff set | 1 | 4 guide cuffs 12 mm wide and 4 anchor cuffs 12 to 19 mm wide, TPU 95A padded saddles with thin side bands and tendon eyelets, 2 mm padded liner, 6 mm hook-and-loop closures | Self (print); liner foam from online retailer | 7.00 | make | Material cost only; saddle shape per FXH-DDR-003
16 Tendon line | 1 | 0.8 mm braided UHMWPE line, 10 m spool | Fishing or outdoor retailer | 8.00 | buy | Indicative
17 Thumb spacer | 1 | TPU 95A ring and web block, the block stitched to the glove | Self (print) | 2.00 | make | Material cost only
18 USB-C charger | 1 | 2S Li-ion charger module with USB-C input, mounted in the pack | Online retailer | 8.00 | buy | Indicative
19 Wiring and consumables | 1 | Wire, connectors, heat shrink, adhesive, 100 uF bulk capacitor, foam pad | Electronics distributor and hardware store | 16.00 | buy | Indicative; not modeled; fixings moved to line 24
20 Idler bearing | 4 | 623ZZ-class ball bearing 3 x 10 x 4 mm on a 3 mm pin, tendon idler | Bearing supplier or online retailer | 1.00 | buy | Indicative
21 Fingertip thimble set | 1 | 4 open-tip thimbles 13 to 19 mm wide on the distal phalanges, TPU 95A 2 mm with 2 mm padded liner | Self (print); liner foam from online retailer | 4.00 | make | Material cost only; FXH-DDR-002 (N2)
22 Balance pulley bearing | 4 | 693ZZ-class ball bearing 3 x 8 x 4 mm on a 3 mm pin, floating balance pulley | Bearing supplier or online retailer | 1.00 | buy | Indicative; FXH-DDR-002 (N3)
23 Electronics tray | 1 | 3D-printed PETG 2 mm plate, 37.5 x 71 mm, on ledges over the cells | Self (print) | 1.00 | make | Material cost only; new in FXH-DDR-003
24 Fixing kit | 1 | 18 brass M3 heat-set inserts 5 mm long; 6 M3 x 8 button-head, 4 M3 x 6 countersunk, 4 aluminium M3 x 8 pan-head, 4 M3 x 8 cap and 4 aluminium M3 x 16 cap screws; 4 M2.2 x 8 self-tapping screws; 8 steel pins 3 mm (4 x 8 mm, 4 x 6.5 mm); cable ties | Hardware store or online retailer | 11.00 | buy | Indicative; new in FXH-DDR-003; price up USD 1 for eight aluminium M3 screws (lid and cover), about USD 0.20 each from fastener retailers against about USD 0.05 for steel, rounded up
25 5 V regulator | 1 | Step-down regulator module, 6 to 9 V in, 5 V 1 A out, for the controller | Electronics distributor | 4.00 | buy | Indicative; new in FXH-DDR-003 (the controller cannot take the pack voltage)

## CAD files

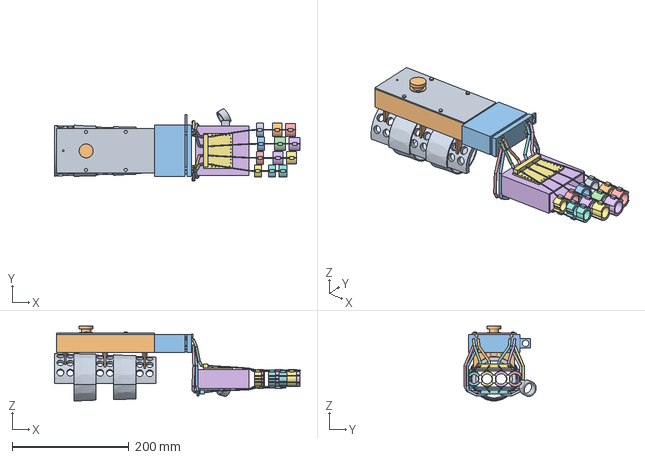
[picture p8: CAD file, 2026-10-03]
cad/step/flexhand-assembly.step
421.5 x 124.2 x 128.0 mm

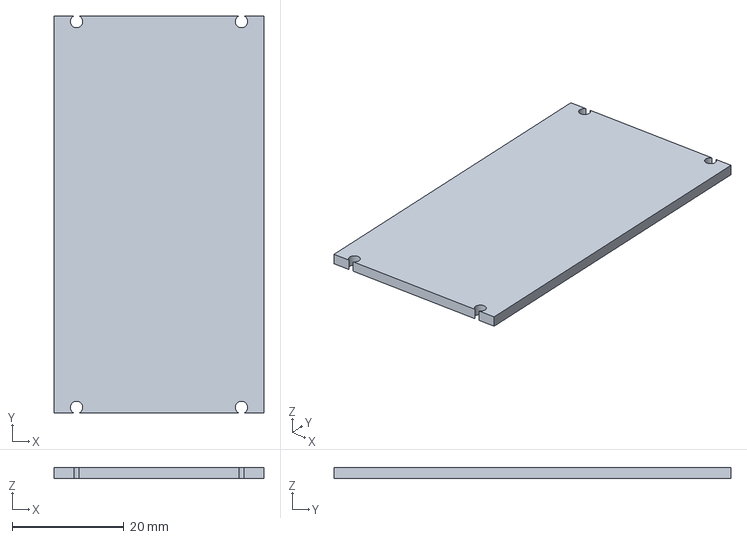
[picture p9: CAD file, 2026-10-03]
cad/step/flexhand-electronics-tray.step
37.5 x 71.0 x 2.00 mm

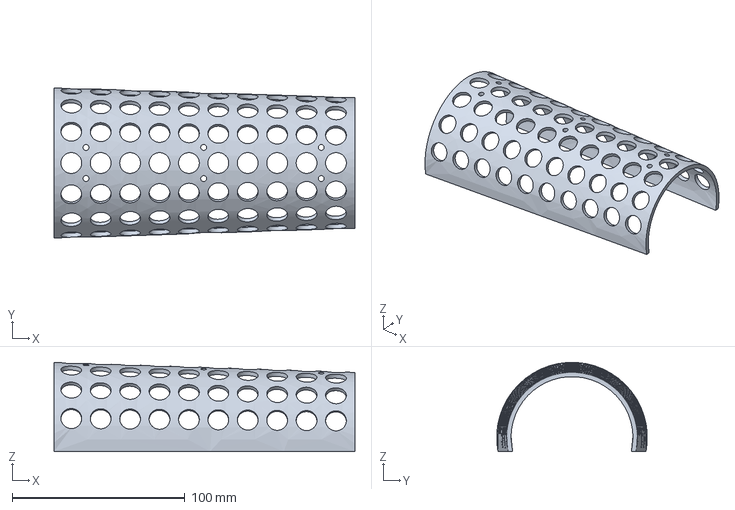
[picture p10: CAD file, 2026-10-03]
cad/step/flexhand-cuff-shell.step
174.0 x 87.0 x 51.5 mm

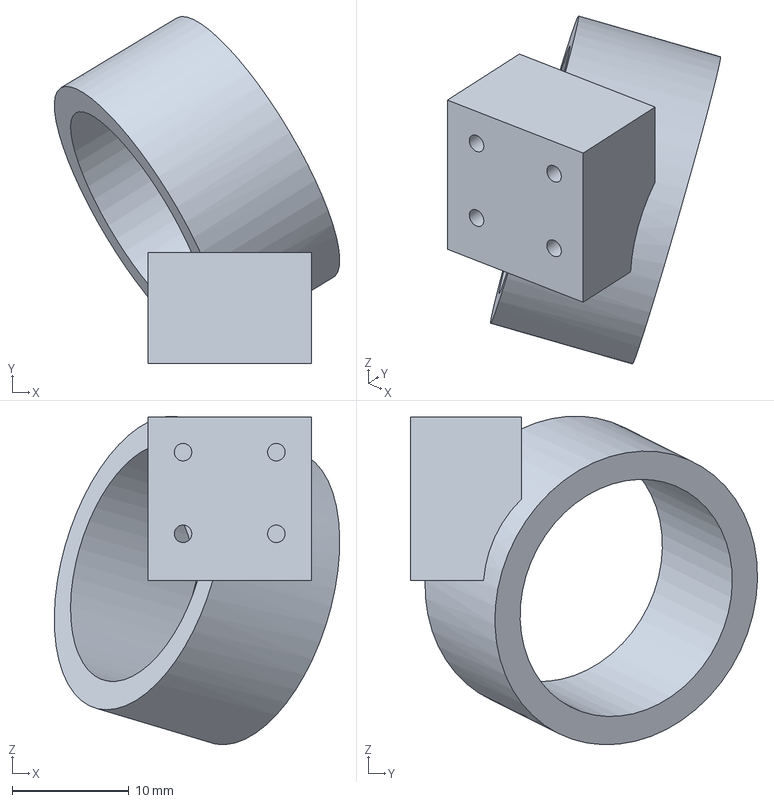
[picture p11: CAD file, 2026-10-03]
cad/step/flexhand-thumb-spacer.step
24.5 x 29.8 x 28.2 mm

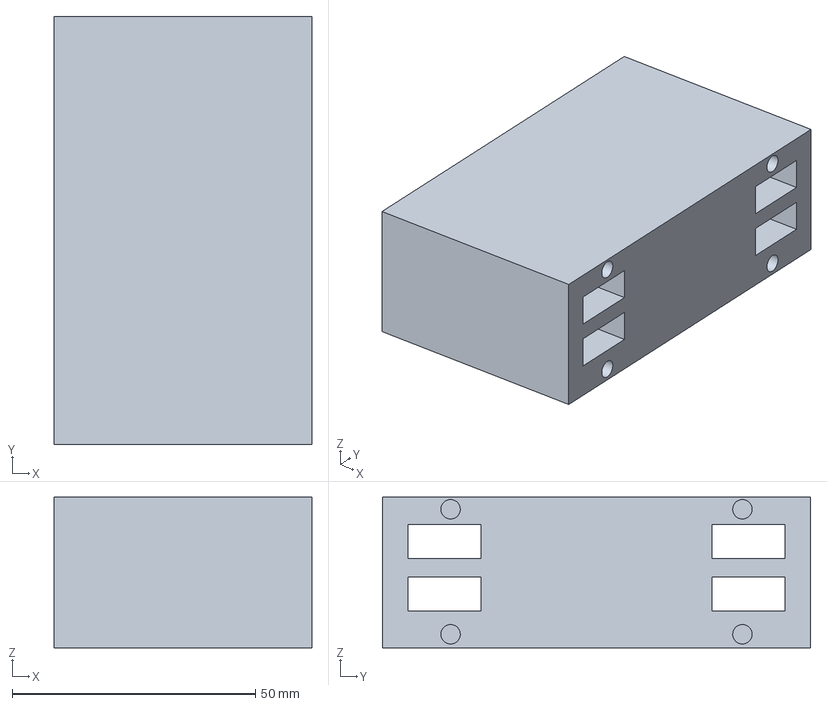
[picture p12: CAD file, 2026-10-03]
cad/step/flexhand-anchor-body.step
53.0 x 88.0 x 31.0 mm

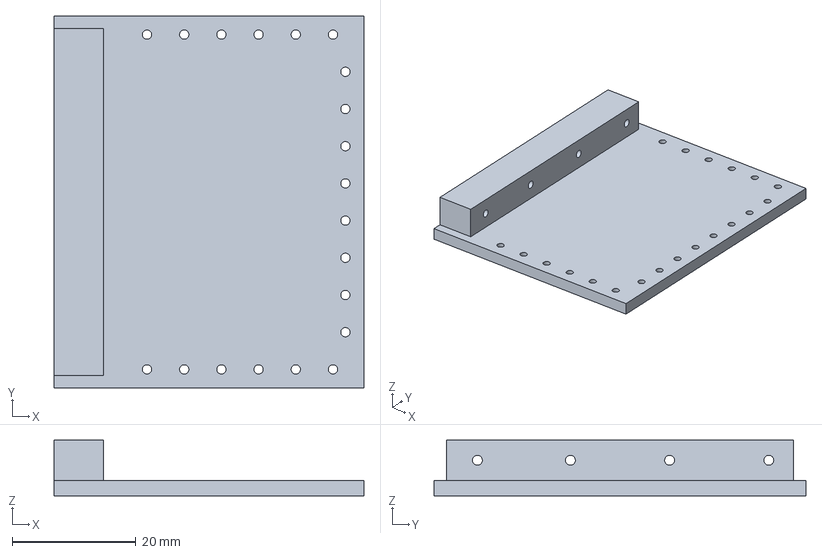
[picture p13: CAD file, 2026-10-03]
cad/step/flexhand-dorsal-plate.step
50.0 x 60.0 x 9.00 mm

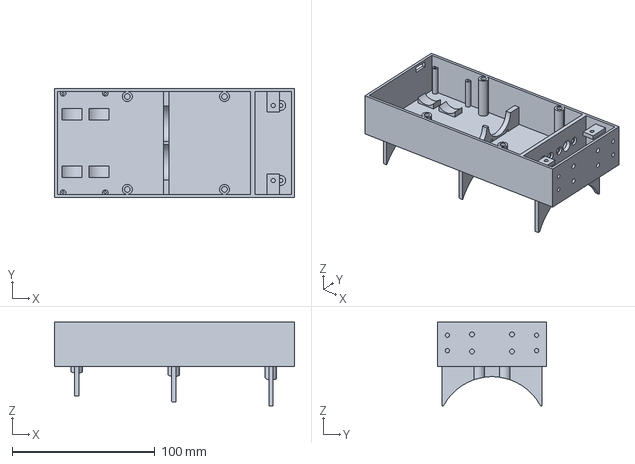
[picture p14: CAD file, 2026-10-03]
cad/step/flexhand-pack-base.step
168.0 x 76.0 x 58.5 mm

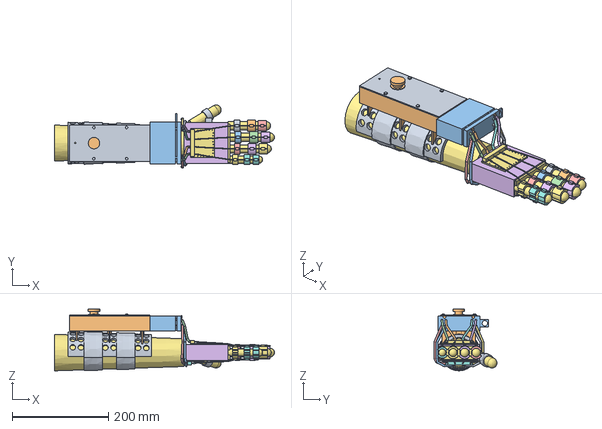
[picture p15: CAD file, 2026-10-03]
cad/step/flexhand-on-forearm.step
457.9 x 131.5 x 128.5 mm

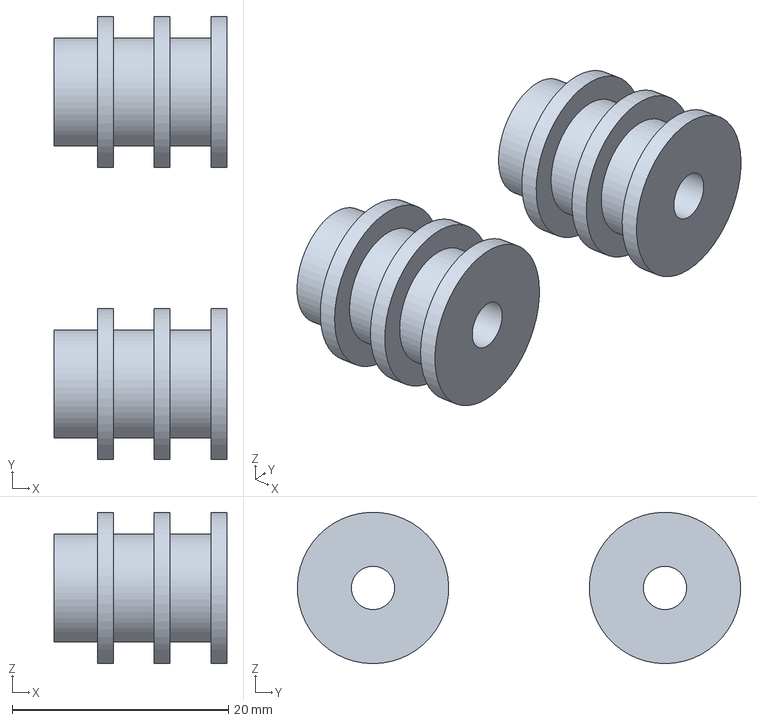
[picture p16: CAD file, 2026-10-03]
cad/step/flexhand-spools.step
16.0 x 41.0 x 14.0 mm

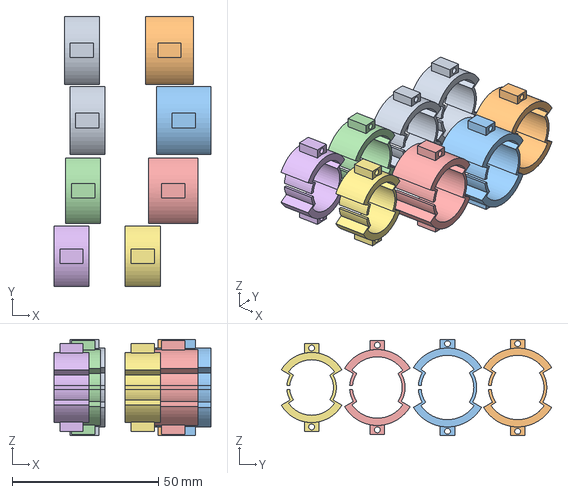
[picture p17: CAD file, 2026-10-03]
cad/step/flexhand-finger-cuffs.step
53.7 x 92.5 x 33.0 mm

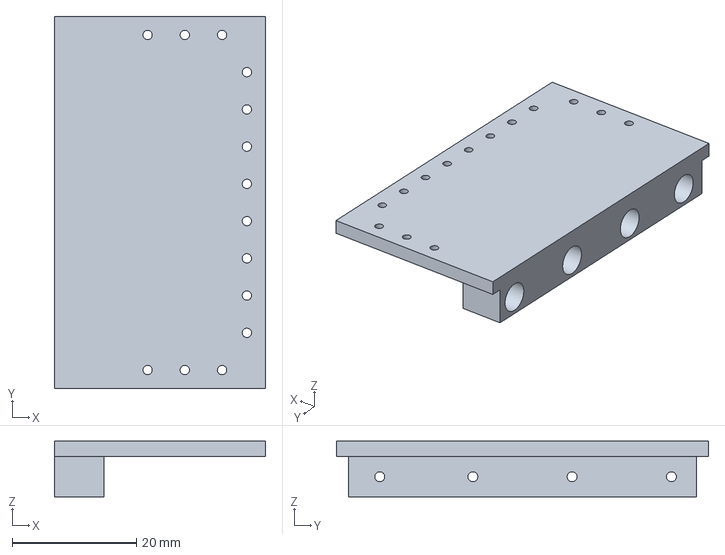
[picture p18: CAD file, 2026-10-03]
cad/step/flexhand-palmar-plate.step
34.0 x 60.0 x 9.00 mm

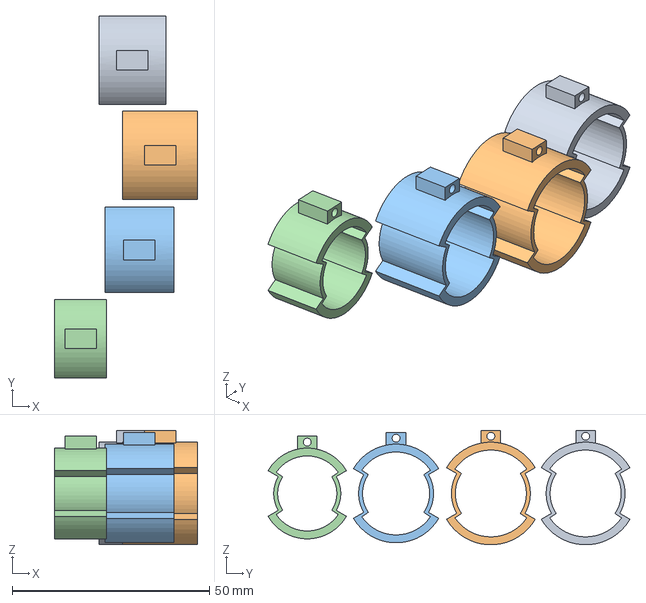
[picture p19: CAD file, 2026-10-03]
cad/step/flexhand-thimbles.step
36.2 x 91.7 x 29.0 mm

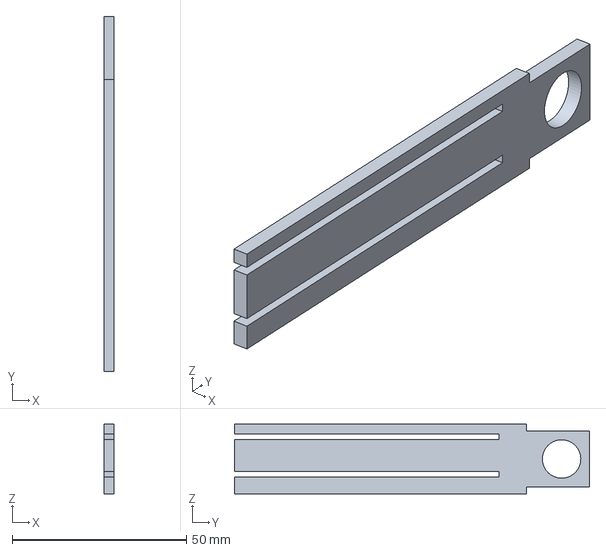
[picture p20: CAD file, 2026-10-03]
cad/step/flexhand-release-plate.step
3.00 x 101.8 x 20.0 mm

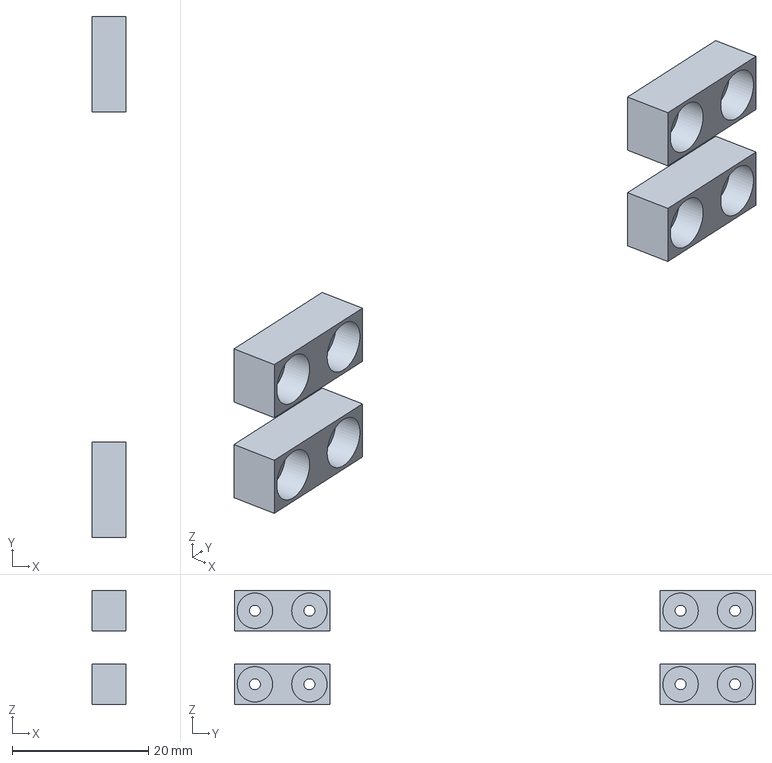
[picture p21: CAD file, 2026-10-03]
cad/step/flexhand-pucks.step
5.00 x 76.5 x 16.8 mm

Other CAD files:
cad/step/flexhand-pack-lid.step
cad/step/flexhand-cover.step
cad/step/flexhand-forearm-cuff.step
cad/step/flexhand-anchor-block.step
cad/stl/flexhand-anchor-block.stl
cad/stl/flexhand-anchor-body.stl
cad/stl/flexhand-assembly.stl
cad/stl/flexhand-cover.stl
cad/stl/flexhand-cuff-shell.stl
cad/stl/flexhand-dorsal-plate.stl
cad/stl/flexhand-electronics-tray.stl
cad/stl/flexhand-finger-cuffs.stl
cad/stl/flexhand-forearm-cuff.stl
cad/stl/flexhand-pack-base.stl
cad/stl/flexhand-pack-lid.stl
cad/stl/flexhand-palmar-plate.stl
cad/stl/flexhand-pucks.stl
cad/stl/flexhand-release-plate.stl
cad/stl/flexhand-spools.stl
cad/stl/flexhand-thimbles.stl
cad/stl/flexhand-thumb-spacer.stl

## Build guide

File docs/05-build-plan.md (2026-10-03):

---
doc_id: FXH-BLD-001
title: FlexHand prototype build plan
project: FlexHand
doc_type: Build plan
version: "0.3"
status: Draft
date: '2026-10-02'
author: Amish Chadha
license: CERN-OHL-S-2.0
revisions:
  - version: "0.1"
    date: '2026-10-01'
    author: Amish Chadha
    change: First build plan; design made constructable (FXH-DDR-003)
  - version: "0.2"
    date: '2026-10-02'
    author: Amish Chadha
    change: 'Release check pass mark and safety stop S6 carry the safety decisions of 2026-10-02 (FXH-DEC-001); no design change'
  - version: "0.3"
    date: '2026-10-02'
    author: Amish Chadha
    change: 'Mass savings tried: aluminium lid and cover screws, thinner pack ribs, larger pocket in the anchor block; forearm unit estimate 712 g'
---

# FlexHand prototype build plan

**Plan, not yet built.** How to build the first proof-of-concept prototype, component by component. Building and testing to it is TRL 4 work. Decisions still to be made are kept in the design decisions register ([docs/06-design-decisions.md](06-design-decisions.md)), not here.

> **Safety:** FlexHand is a research and educational prototype, not a medical device. It pulls on fingers that may be spastic or unable to feel, its gearboxes hold position when unpowered, and it carries a lithium-ion pack. This plan builds and bench-checks a prototype; nothing in it allows the device to be worn by a person. Follow the safety stops in section 6.

## 1. What you are building

Figure 1. Every component, pulled apart and numbered in build order

*Figure 1. Every component pulled apart and numbered in build order. The pictures in this plan show the right-hand device; a left-hand device is its mirror image.*

The prototype is one FlexHand for a medium adult hand: a printed motor pack screwed onto a perforated forearm cuff, with an anchor block on its front end, and a fingerless glove carrying two plates, a thumb spacer, eight finger cuffs and four fingertip thimbles. Eight tendons run from the anchor block to the fingers inside eight Bowden sheaths. Figure 1 shows the 26 components in the order you make or fit them. Seventeen are made: fourteen 3D prints (pack base, anchor block, cuff shell, tray, lid, spools, dorsal and palmar plates, thumb spacer, finger cuffs, thimbles, pucks, release plate and cover), the cut foam liner, eight small breakaway couplings and the sheaths cut from bicycle shift housing. Everything else is bought: two gearmotors, bearings, cells, small electronic modules, the stop button, the glove, the straps, tendon line and fixings. The work is 3D printing in PETG and TPU, pressing in heat-set inserts, light drilling and tapping, stitching, tying and crimping line, and wiring bought modules. The parts cost about USD 304, from the bill of materials.

## 2. What changed to make it buildable

The concept showed what FlexHand does; many of its parts could not be made or fixed as drawn. Each change below keeps what FlexHand does, and all of them are recorded in decision record FXH-DDR-003, open for Amish's review.

*Table 1. Changes from the concept.*

| Component | The concept had | The buildable design has | Why |
| --- | --- | --- | --- |
| Pack on the cuff | No fixing; the cuff cut into the pack floor | Floor raised 4 mm; six screws up through the cuff into inserts in the pack's ribs (Figure 3) | The pack must not move under the sheaths' push |
| Straps | Inside the foam liner | Over the cuff, under the pack between its ribs, then round the forearm (Figure 11) | How a strap holds a half shell |
| Gearmotors | Floating, no fixing | A printed bulkhead holds each gearbox face on two screws; a cradle holds the motor's rear (Figure 4) | The gearbox face is the motor's mounting face |
| Spools and idlers | Idlers cut into 20 mm spool flanges; no pins | 14 mm flanges and a set-screw hub; idlers on steel pins in a printed post and shelf (Figure 5) | Every part has room and a support |
| Rear bay | Boards overlapping and floating; cells loose; no 5 V supply for the controller | Cells in saddles under a screwed-down tray; boards laid out on the tray; a 5 V regulator added (Figure 6) | Every part has a seat and a fixing |
| Anchor block | 44 mm long, no room for couplings and springs, channels not in line with the tendons, no fixing | 53 mm long, 88 mm wide, four channels in line with the tendon exits, screwed to the pack (Figures 8 and 9) | The channel must hold everything that moves with the line |
| Quick release | A lever with no mechanism | A red release plate with a finger loop: pull it out and all eight sheaths and tendons go slack (Figure 9) | One pull, by hand, with no tools |
| Slack springs and stop beads | Eight of each, with no place | Four springs, one per pulley line; the stop beads at the hand end (Figure 19) | Same effect, with room for both |
| Finger cuffs and thimbles | Full rings that overlapped the next finger's; no tendon eyelets; no closure | Padded saddles top and bottom with thin sides, eyelets and end tabs, a hook-and-loop closure; fingers held slightly apart by the glove (Figure 24) | Same contact areas, and they fit side by side |
| Hand plates and sheaths | Sheaths ending on the plates with no stop; flexor sheaths through the wrist | Printed stop blocks on the plates; sheaths routed round the wrist (Figure 19) | A sheath needs a seat at both ends |
| Pack and cuff position | Pack 160 mm long | Pack 168 mm long, moved 16 to 24 mm toward the elbow; cuff moved 20 mm | Room for the bulkhead and longer block, which still stops 7 mm short of the wrist |

## 3. Making the components

Make and check each component before the assembly step that needs it. Sizes are in millimetres. "Thumb side" and "little-finger side" are as worn, palm down; "elbow end" and "wrist end" are along the forearm. Print tolerance is 0.2 mm on fits and 0.5 mm elsewhere unless a step says otherwise; drawings do not carry tolerances before TRL 4. Every printed part is printed in PETG unless its section says TPU or PA12.

### 3.1 Pack base

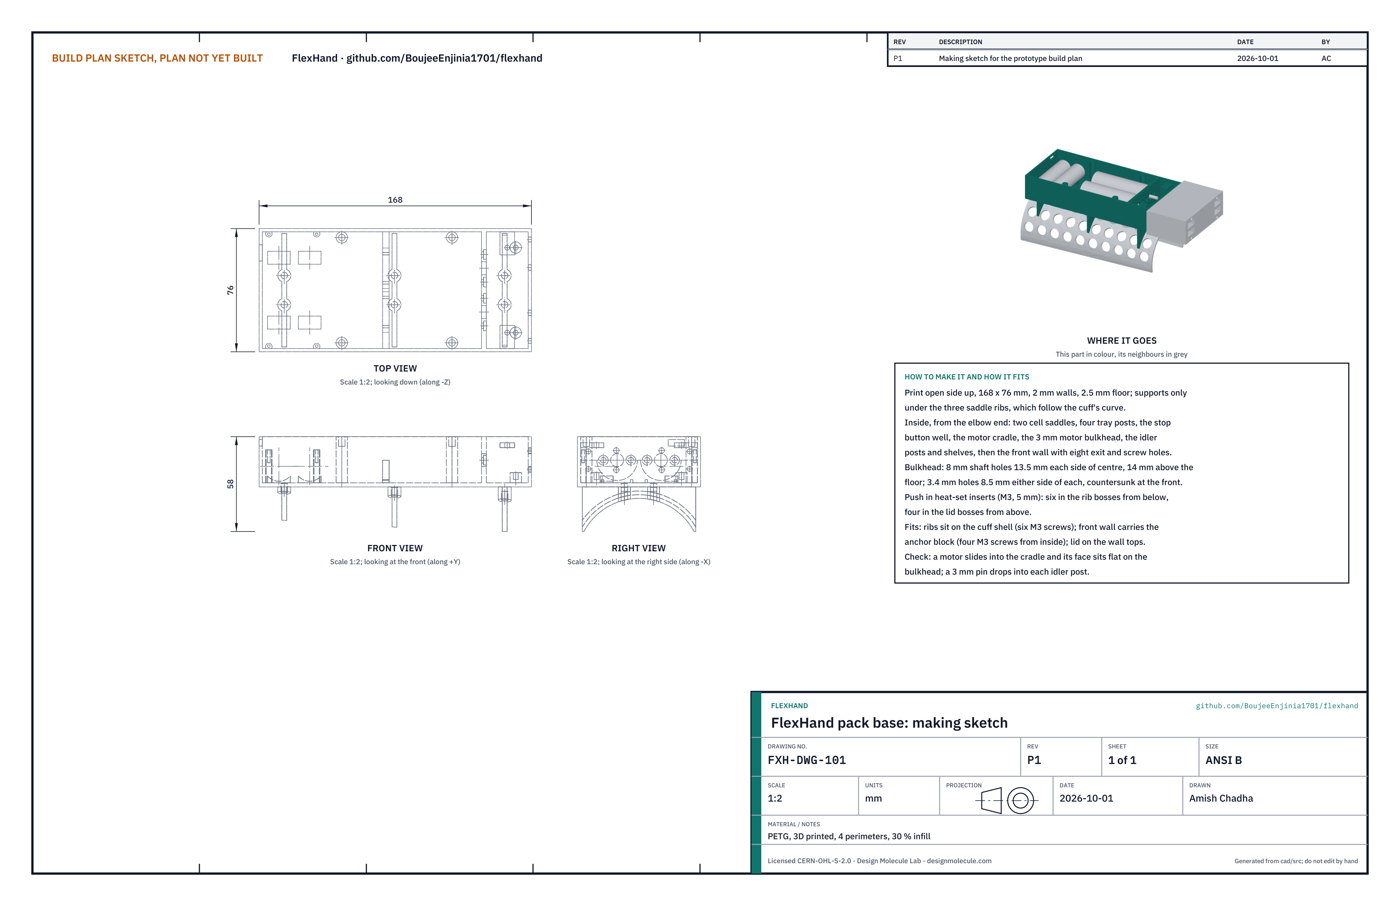
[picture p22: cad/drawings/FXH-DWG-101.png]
Figure 2. Making sketch of the pack base


*Figure 2. Pack base making sketch (FXH-DWG-101).*

**What it is and what it is made from.** The open box that carries the motors, spools, idlers, cells and electronics, with three saddle ribs underneath that sit on the cuff. PETG, printed, four perimeters, 30 % infill.

**How to make it.**

1. Print it open side up, 168 long and 76 wide, with 2 mm walls and a 2.5 mm floor. Use supports only under the three saddle ribs, which follow the cuff's curve underneath.
2. Clean the eight 3 mm and 3.4 mm holes in the front wall with a drill held in the fingers: two pairs of tendon exit holes 31.25 to each side of the centre line, 5.4 above and below the motor axis height; four screw holes 14 to each side, 6 above and below it.
3. Check the bulkhead holes: an 8 mm shaft hole 13.5 to each side of centre, 14 above the floor, and a 3.4 mm hole 8.5 either side of each shaft hole, countersunk on the front face.
4. Press in ten M3 heat-set inserts (5 mm long) with a soldering iron at about 230 °C: six from below into the rib bosses (9 to each side of the centre line) and four from above into the lid bosses.
5. Check that a 3 mm pin drops into the hole in each idler post and through each idler shelf.

**How it fits the parts next to it.**

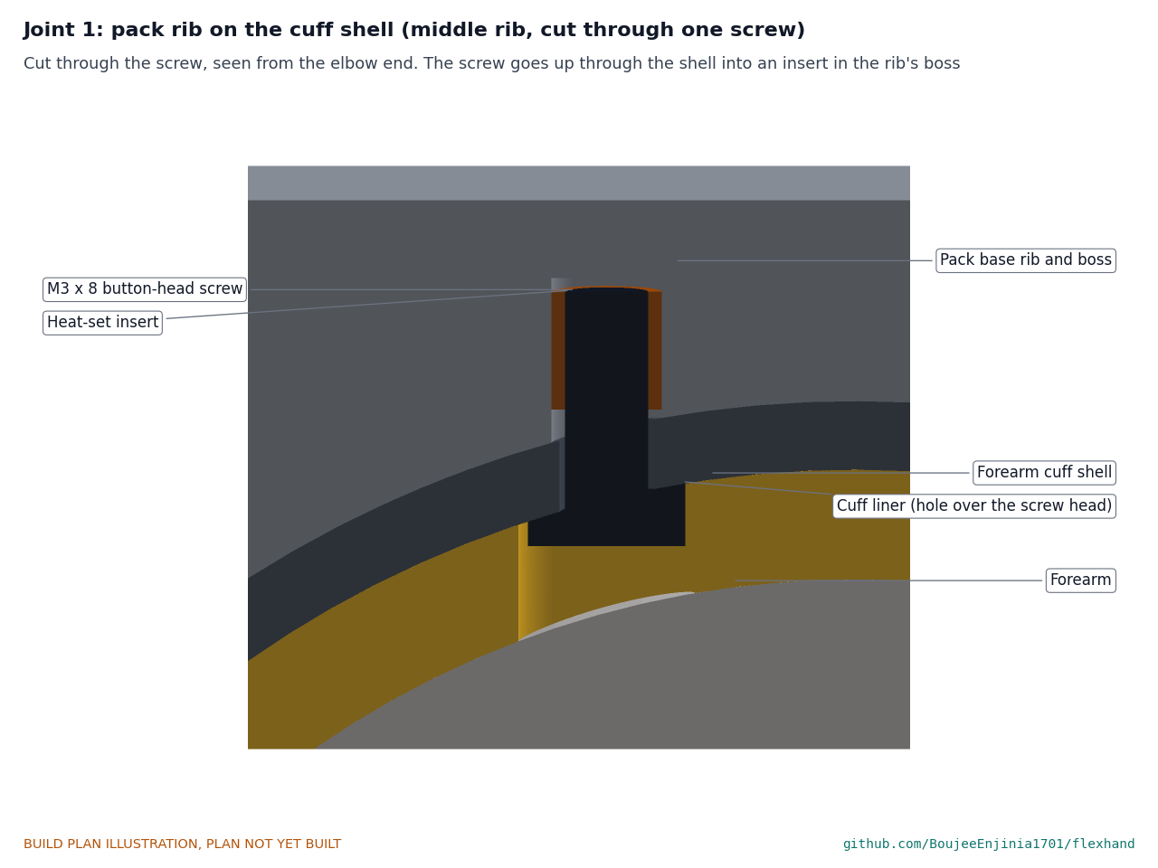
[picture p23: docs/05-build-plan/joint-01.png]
Figure 3. Joint 1: pack rib on the cuff shell


*Figure 3. Each rib sits on the cuff shell; a button-head screw goes up through the shell into the insert in the rib's boss. The liner has a hole over the screw head.*

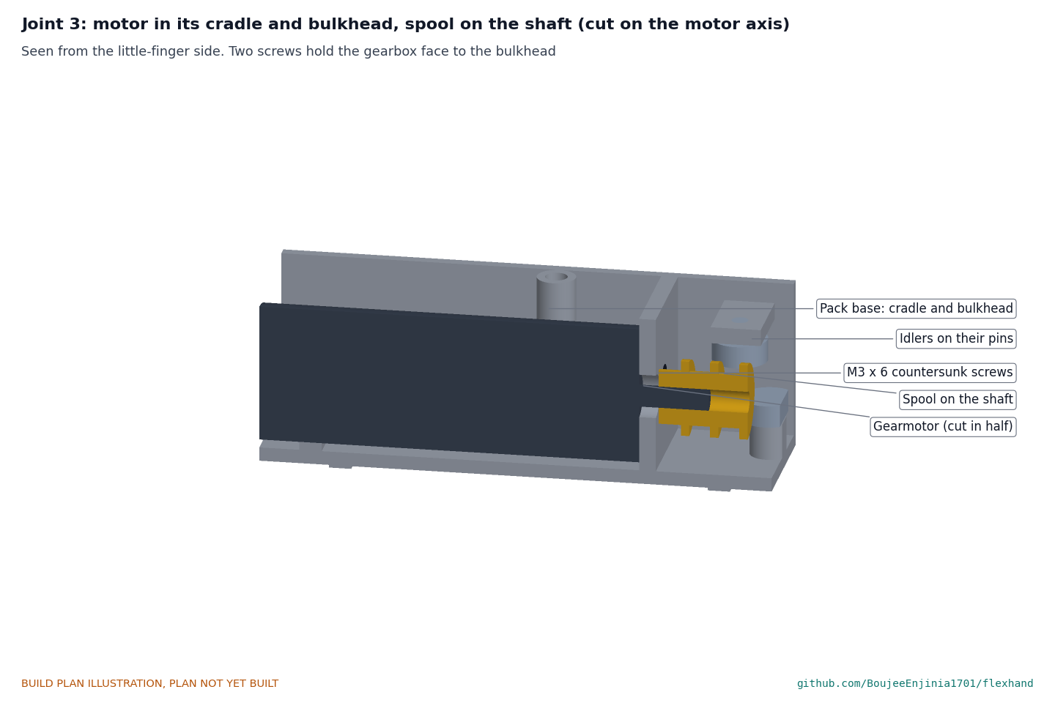
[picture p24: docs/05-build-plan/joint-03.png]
Figure 4. Joint 3: motor in its cradle and bulkhead


*Figure 4. The gearbox face sits flat on the back of the bulkhead, held by two countersunk screws from the front; the motor's rear sits in the cradle with a cable tie. The spool hub runs 0.5 mm in front of the bulkhead.*

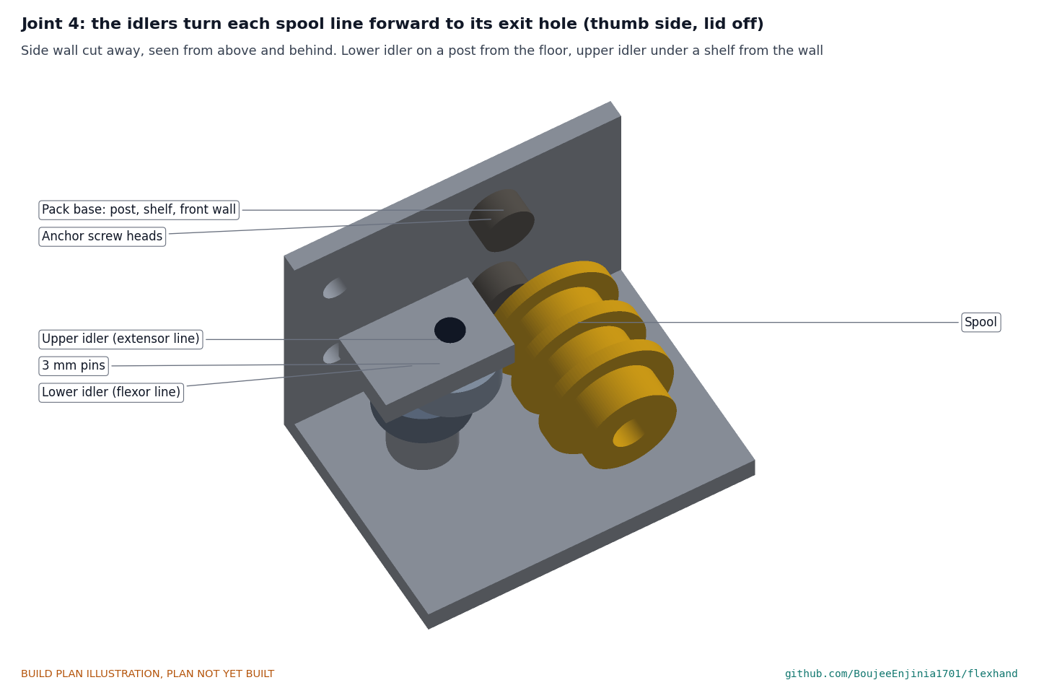
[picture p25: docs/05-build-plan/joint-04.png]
Figure 5. Joint 4: the idlers


*Figure 5. The lower idler turns on a pin in a post from the floor; the upper idler on a pin pushed down through a shelf from the side wall. Each turns its spool line forward to its exit hole.*

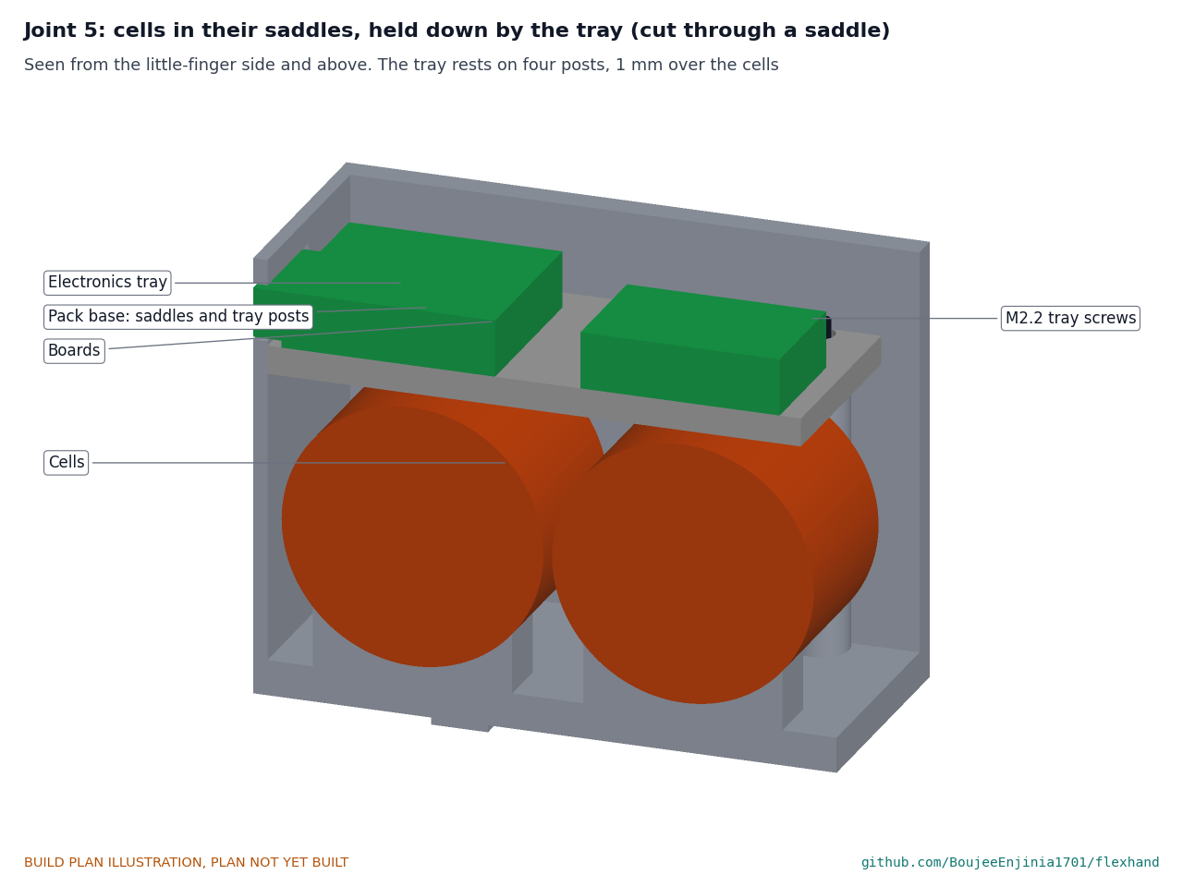
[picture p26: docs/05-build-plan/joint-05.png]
Figure 6. Joint 5: cells and tray


*Figure 6. The cells sit in printed saddles; the tray rests on four posts 1 mm above them, with a foam pad between, and its four screws hold the cells down.*

The three ribs sit on the cuff shell at 18.5, 86.5 and 154.5 from the cuff's elbow end, on the solid strips between hole columns; the straps pass through the gap between floor and cuff between the ribs. The anchor block's back face sits flat on the front wall. The lid sits on the wall tops.

**Check before moving on.** A gearmotor slides into the cradle and its face sits flat on the bulkhead with both screw holes in line; the floor is flat within 0.5 mm.

### 3.2 Anchor block

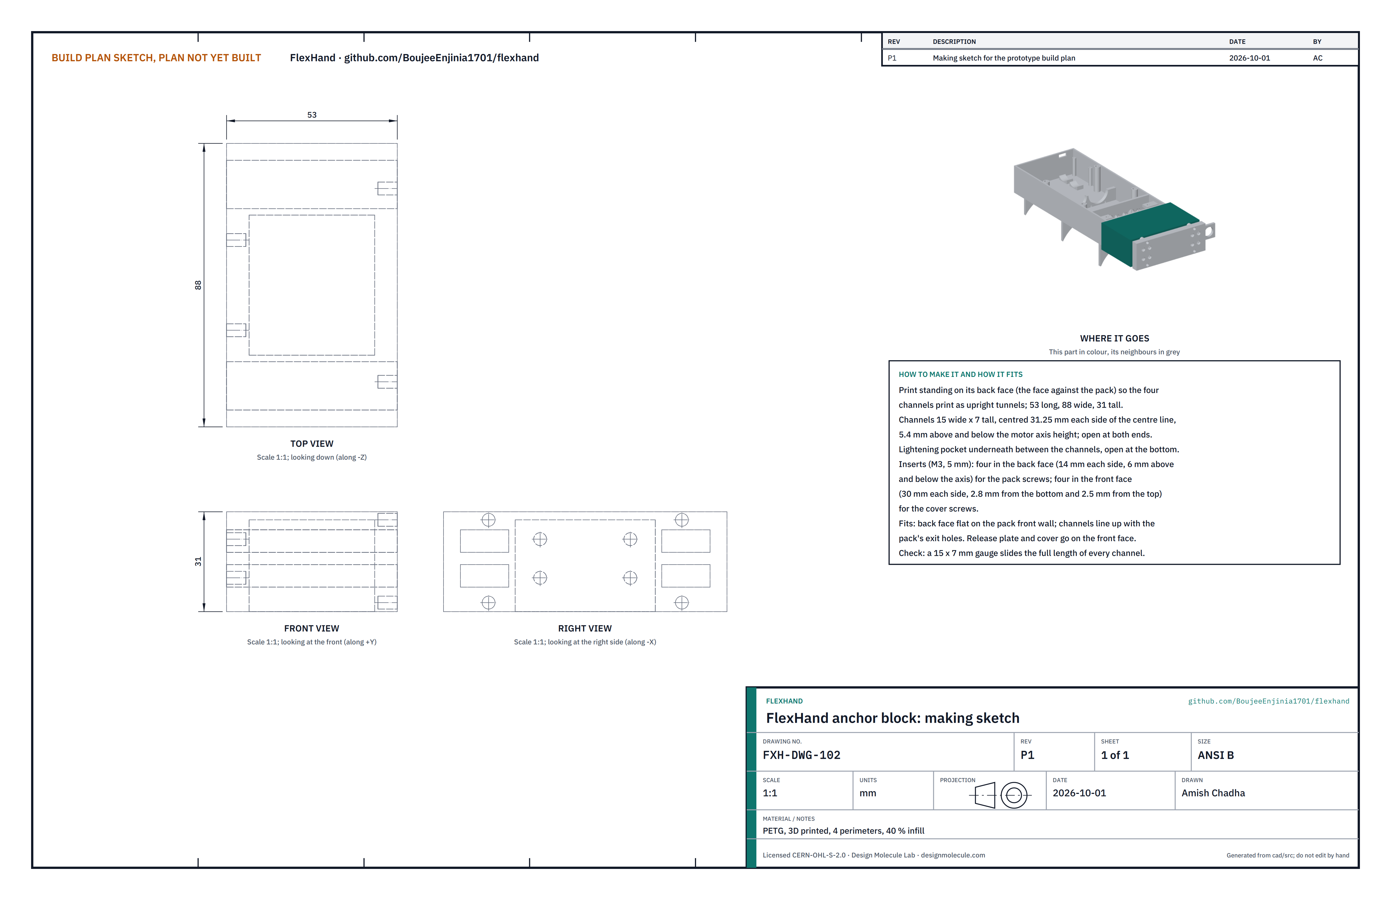
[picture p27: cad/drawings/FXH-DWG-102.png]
Figure 7. Making sketch of the anchor block


*Figure 7. Anchor block making sketch (FXH-DWG-102).*

**What it is and what it is made from.** The block on the front of the pack in which each spool line's balance pulley shares its pull between two fingers. PETG, printed, four perimeters, 40 % infill.

**How to make it.**

1. Print it standing on its back face (the face that goes against the pack) so the four channels print as upright tunnels. It is 53 long, 88 wide and 31 tall.
2. Check the channels: 15 wide by 7 tall, centred 31.25 to each side of the centre line and 5.4 above and below the motor axis height, open at both ends. A 15 by 7 gauge must slide through each.
3. Press in eight M3 inserts: four in the back face (14 to each side of centre, 6 above and below the motor axis height) for the pack screws, and four in the front face (30 to each side, 2.8 from the bottom and 2.5 from the top) for the cover screws.

**How it fits the parts next to it.**

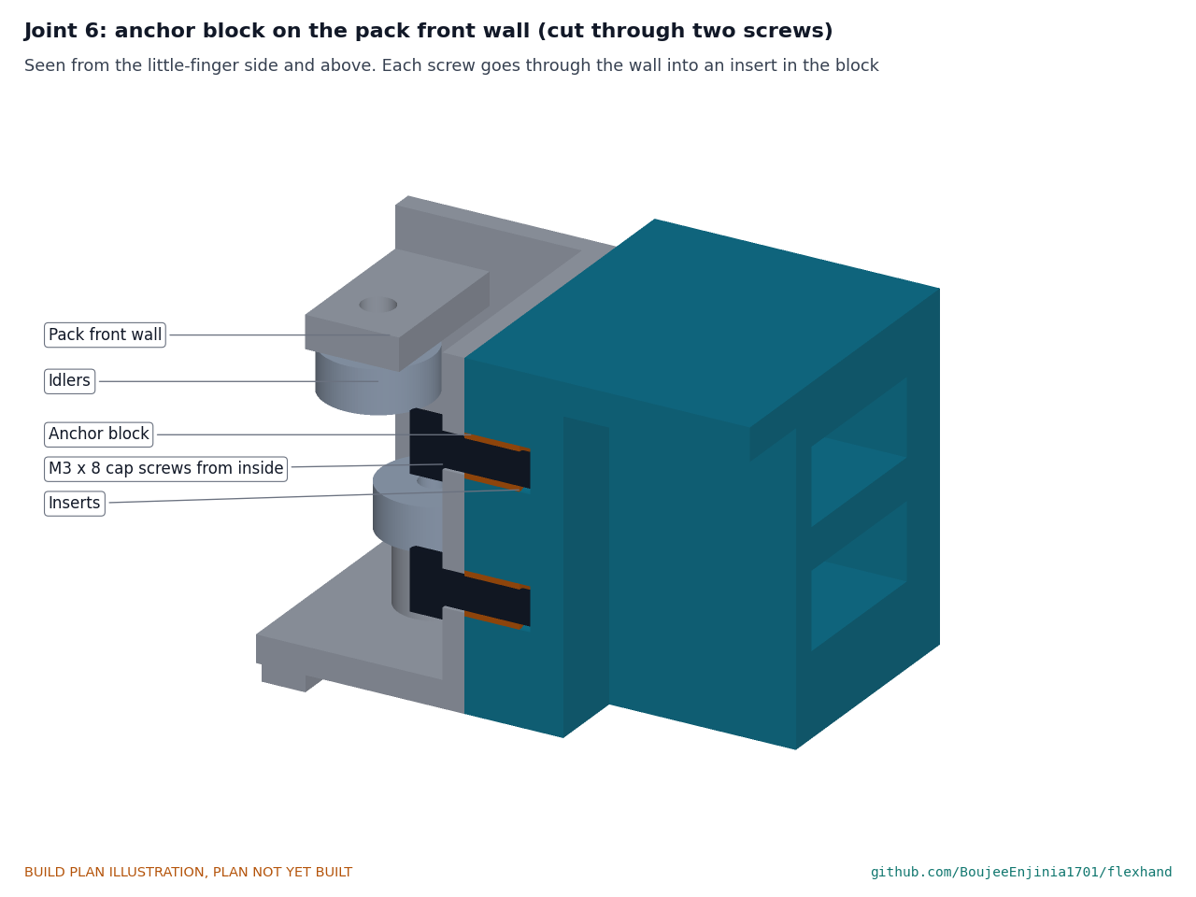
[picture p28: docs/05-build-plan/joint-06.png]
Figure 8. Joint 6: anchor block on the pack front wall


*Figure 8. Four cap screws from inside the pack go through the front wall into the block's inserts. The pack's exit holes open into the block's channels.*

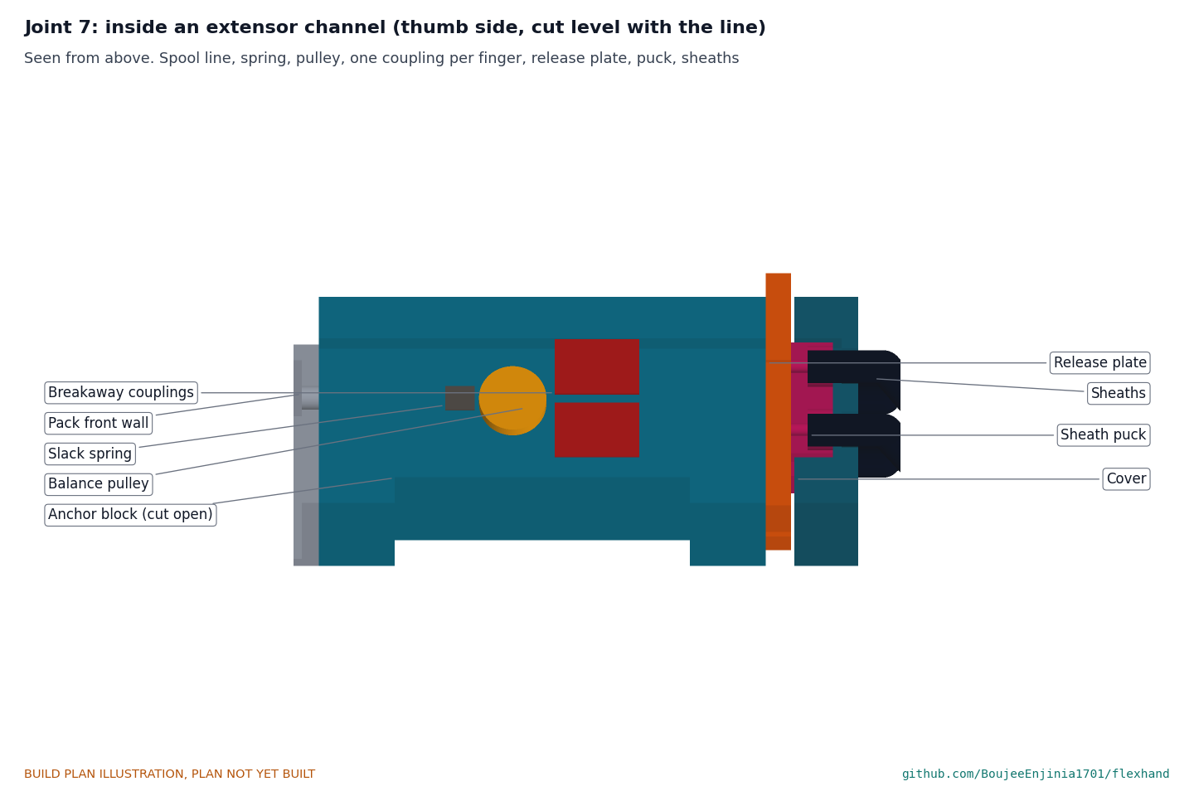
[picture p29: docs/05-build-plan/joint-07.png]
Figure 9. Joint 7: inside a channel


*Figure 9. Inside one channel, from the pack end: the spool line and its slack spring, the balance pulley, one breakaway coupling for each finger, then the release plate, the sheath puck in its pocket in the cover, and the two sheaths.*

The back face sits flat on the pack front wall, with the channels in line with the exit holes. The release plate slides in a 3.4 gap between the front face and the cover. Each balance pulley rides in its channel with 30 of travel, more than the 29.8 stroke.

**Check before moving on.** Held against the pack's front wall, a 2 mm rod through each exit hole enters its channel without touching the sides.

### 3.3 Forearm cuff shell

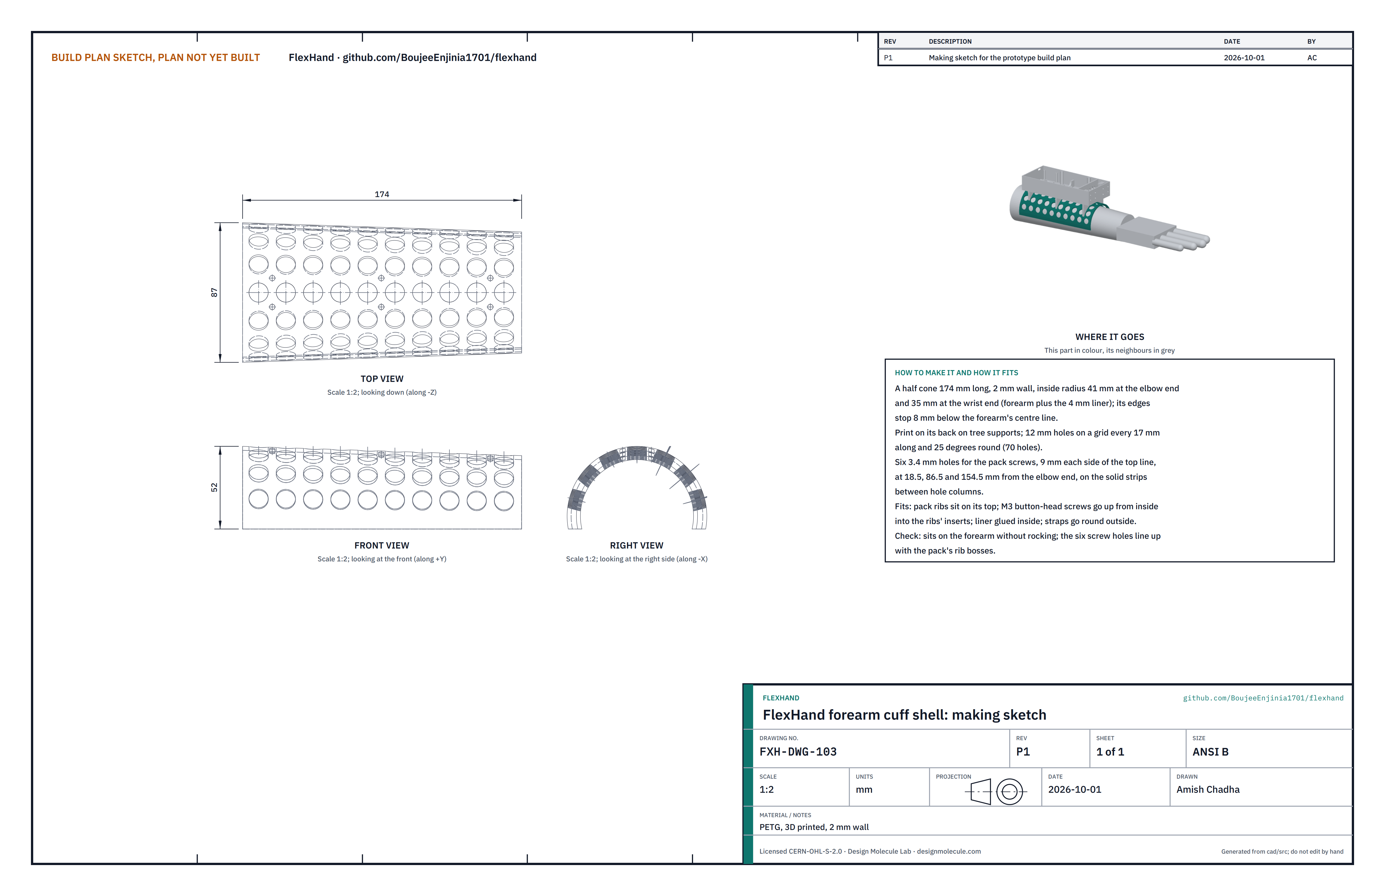
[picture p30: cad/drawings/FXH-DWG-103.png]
Figure 10. Making sketch of the forearm cuff shell


*Figure 10. Forearm cuff shell making sketch (FXH-DWG-103).*

**What it is and what it is made from.** The perforated half shell that spreads the pack's weight over the back of the forearm. PETG, printed, 2 mm wall.

**How to make it.**

1. Print it lying on its back on tree supports: a half cone 174 long, inside radius 41 at the elbow end and 35 at the wrist end, with its edges 8 below the forearm's centre line.
2. Check the 70 holes of 12 mm, on a grid every 17 along and every 25° round.
3. Check the six 3.4 mm screw holes, 9 to each side of the top line at 18.5, 86.5 and 154.5 from the elbow end. They sit on the solid strips between hole columns.
4. Break every edge so nothing sharp can touch the skin.

**How it fits the parts next to it.**

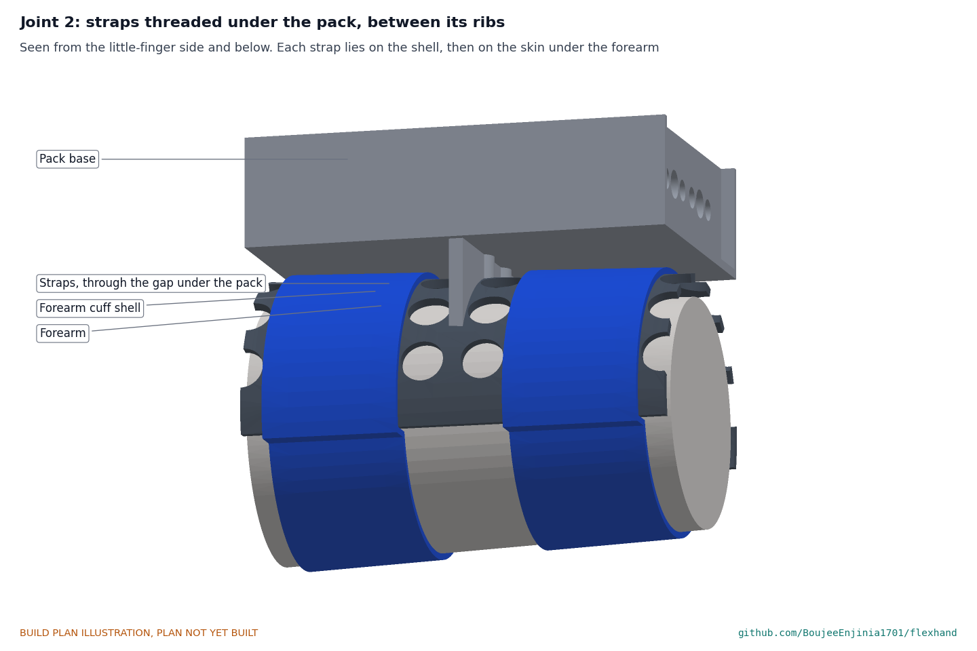
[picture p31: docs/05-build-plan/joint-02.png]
Figure 11. Joint 2: straps under the pack


*Figure 11. Each strap lies over the shell, passes through the gap under the pack between two ribs, then wraps the skin under the forearm.*

The pack's ribs sit on its top with six M3 x 8 button-head screws coming up from inside (Figure 3). The liner is glued inside it after the pack is on. The two straps lie over it, 52.5 and 120.5 from the elbow end.

**Check before moving on.** On a forearm form or a 70 to 80 mm tube, the shell does not rock, and the six screw holes line up with the pack's rib bosses.

### 3.4 Cuff liner

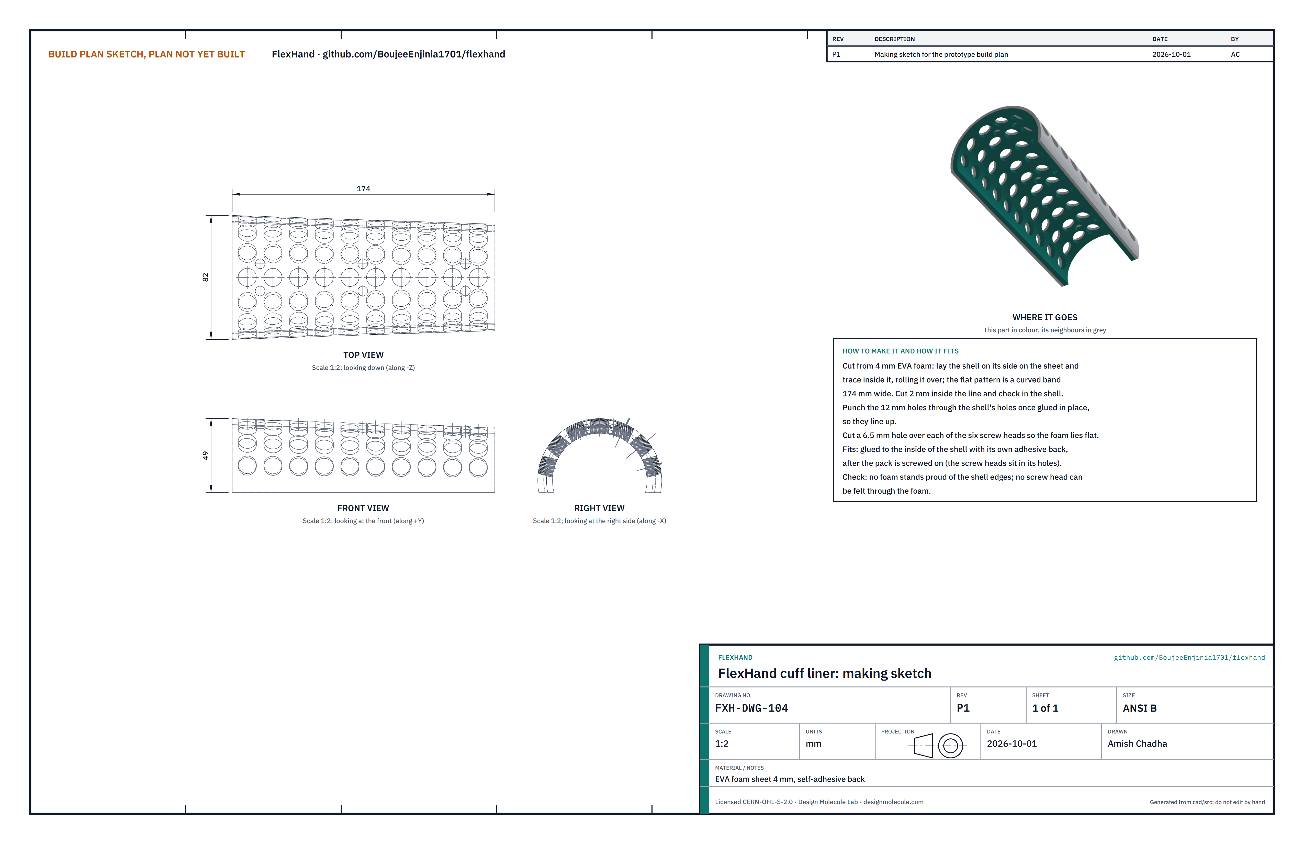
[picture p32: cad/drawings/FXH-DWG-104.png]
Figure 12. Making sketch of the cuff liner


*Figure 12. Cuff liner making sketch (FXH-DWG-104).*

**What it is and what it is made from.** The 4 mm foam lining of the cuff shell. EVA foam sheet, 4 mm, with a self-adhesive back.

**How to make it.**

1. Lay the shell on its side on the foam and trace its inside edge while rolling it over; the pattern is a curved band 174 wide. Cut 2 mm inside the line and check the fit in the shell.
2. Mark and cut a 6.5 mm hole over each of the six screw heads.
3. After it is stuck in (step 4), punch the 12 mm holes through the shell's holes so they line up.

**How it fits the parts next to it.** Stuck to the inside of the shell, edge to edge, with the six screw heads in its holes.

**Check before moving on.** No foam stands proud of the shell's edges and no screw head can be felt through it.

### 3.5 Spools (make 2)

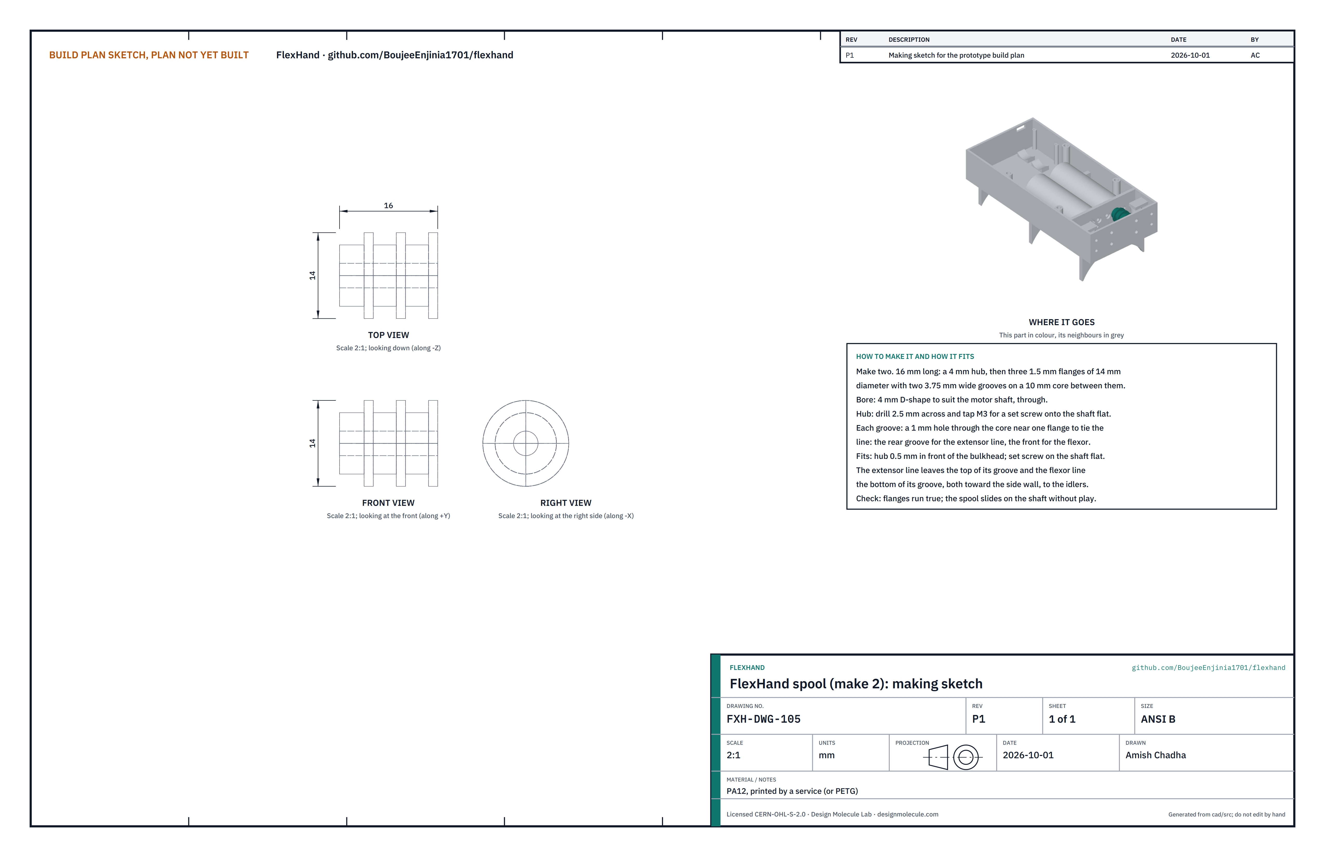
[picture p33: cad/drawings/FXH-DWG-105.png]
Figure 13. Making sketch of the spool


*Figure 13. Spool making sketch (FXH-DWG-105).*

**What it is and what it is made from.** The two-groove drum on each motor shaft: one groove pulls the extensor line while the other pays out the flexor line. PA12 from a print service (PETG works for a first build).

**How to make it.**

1. Print two, 16 long: a 4 mm hub, then three 1.5 mm flanges of 14 mm diameter with two 3.75 mm grooves on a 10 mm core between them.
2. Open the bore to a snug fit on the motor's 4 mm shaft with its flat.
3. Drill 2.5 mm across the hub and tap M3 for a set screw that bears on the shaft flat.
4. Drill a 1 mm hole through the core beside one flange in each groove, for tying the line.

**How it fits the parts next to it.** The hub sits 0.5 in front of the bulkhead, set screw on the shaft flat (Figure 4). The rear groove takes the extensor line, which leaves the top of the groove toward the side wall; the front groove takes the flexor line, which leaves the bottom of its groove (Figure 5).

**Check before moving on.** The flanges run true when the shaft is turned by hand.

### 3.6 Breakaway couplings (make 8)

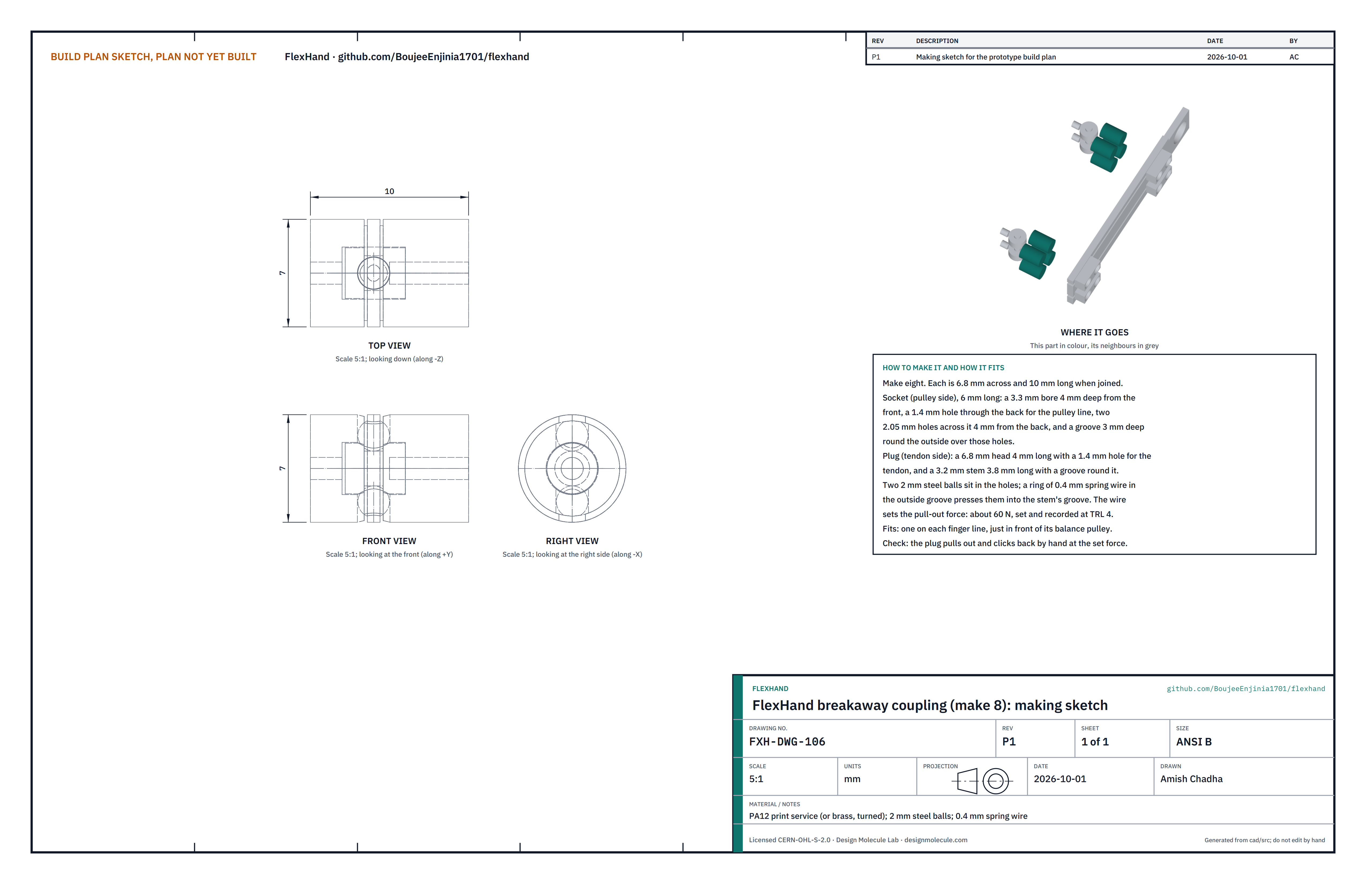
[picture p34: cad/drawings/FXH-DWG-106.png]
Figure 14. Making sketch of the breakaway coupling


*Figure 14. Breakaway coupling making sketch (FXH-DWG-106), drawn larger than full size.*

**What it is and what it is made from.** A two-part link in each finger's line that pulls apart if that tendon's pull passes about 60 N. Socket and plug in PA12 from a print service (or turned brass), two 2 mm steel balls and a ring of 0.4 mm spring wire.

**How to make it.**

1. Socket, 6.8 across and 6 long: a 3.3 mm bore 4 deep from the front, a 1.4 mm hole through the back for the pulley line, two 2.05 mm holes across it 4 from the back, and a groove 3 mm deep round the outside over those holes.
2. Plug: a 6.8 head 4 long with a 1.4 mm hole for the tendon, and a 3.2 stem 3.8 long with a groove round it.
3. Push the stem into the socket, drop a ball into each hole, and spring the wire ring into the outside groove over them.
4. Check the pull-out force on a spring balance and mark each coupling; a thicker or thinner wire ring raises or lowers it. The aim is about 60 N; the force is set and recorded at TRL 4.

**How it fits the parts next to it.** One in each finger's line just in front of its balance pulley, two side by side in each channel (Figure 9). The socket is tied to the line round the pulley; the plug is tied to the tendon.

**Check before moving on.** Each plug pulls out and clicks back by hand at its set force.

### 3.7 Electronics tray

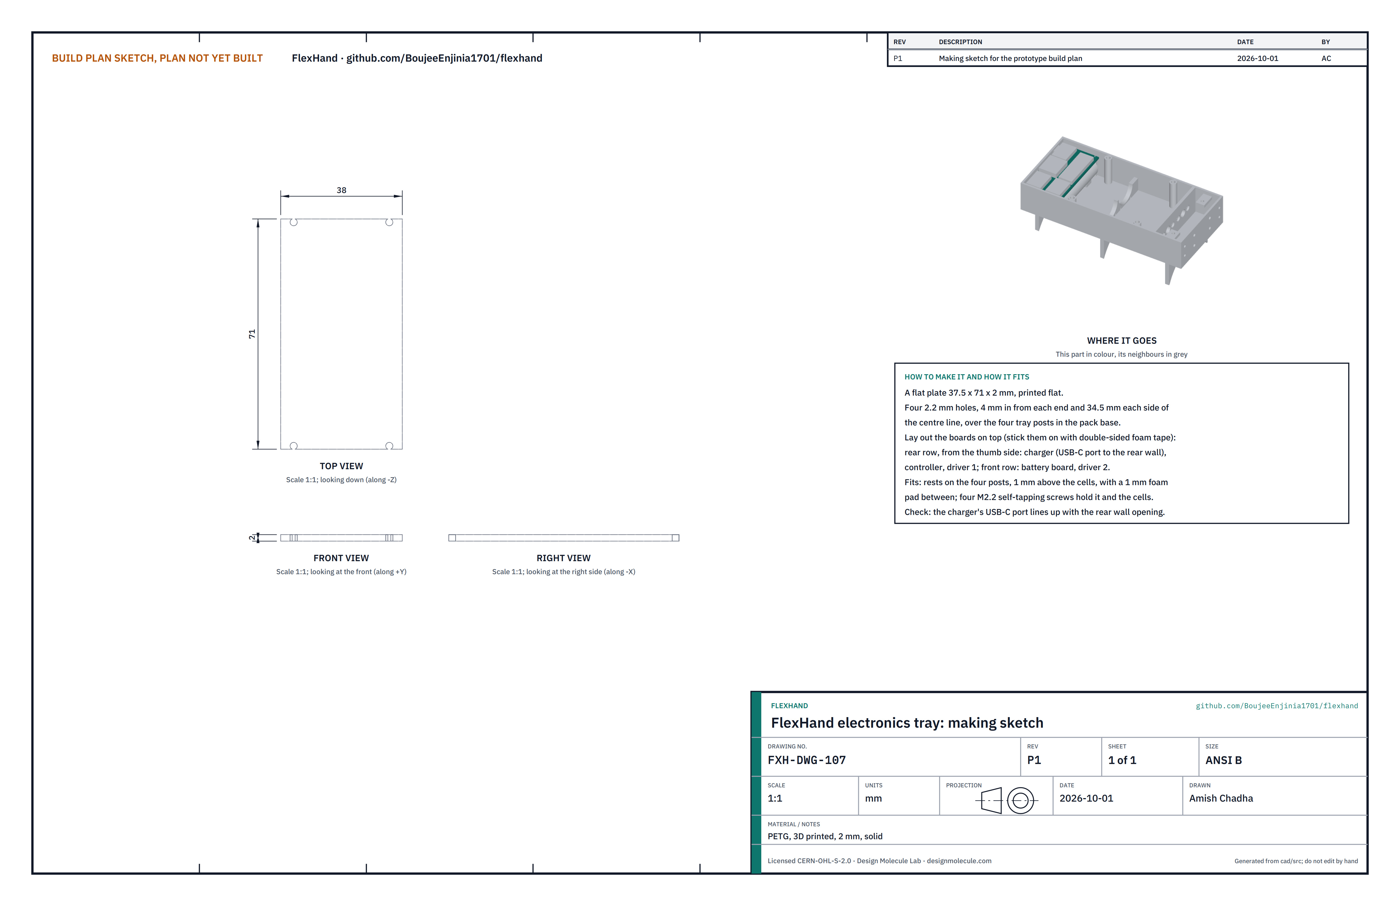
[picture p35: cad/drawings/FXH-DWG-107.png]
Figure 15. Making sketch of the electronics tray


*Figure 15. Electronics tray making sketch (FXH-DWG-107).*

**What it is and what it is made from.** A flat plate over the cells that carries the electronic modules. PETG, printed, 2 mm, solid.

**How to make it.**

1. Print it flat, 37.5 by 71 by 2.
2. Check the four 2.2 mm holes, 4 in from each end and 34.5 to each side of the centre line.
3. Lay out the modules on it with double-sided foam tape: in the row at the elbow end, from the thumb side, the charger (its USB-C port to the rear wall), the controller and motor driver 1; in the front row, the battery board and motor driver 2.
4. Wire the modules as Figure 16 shows, leaving the cell leads free.

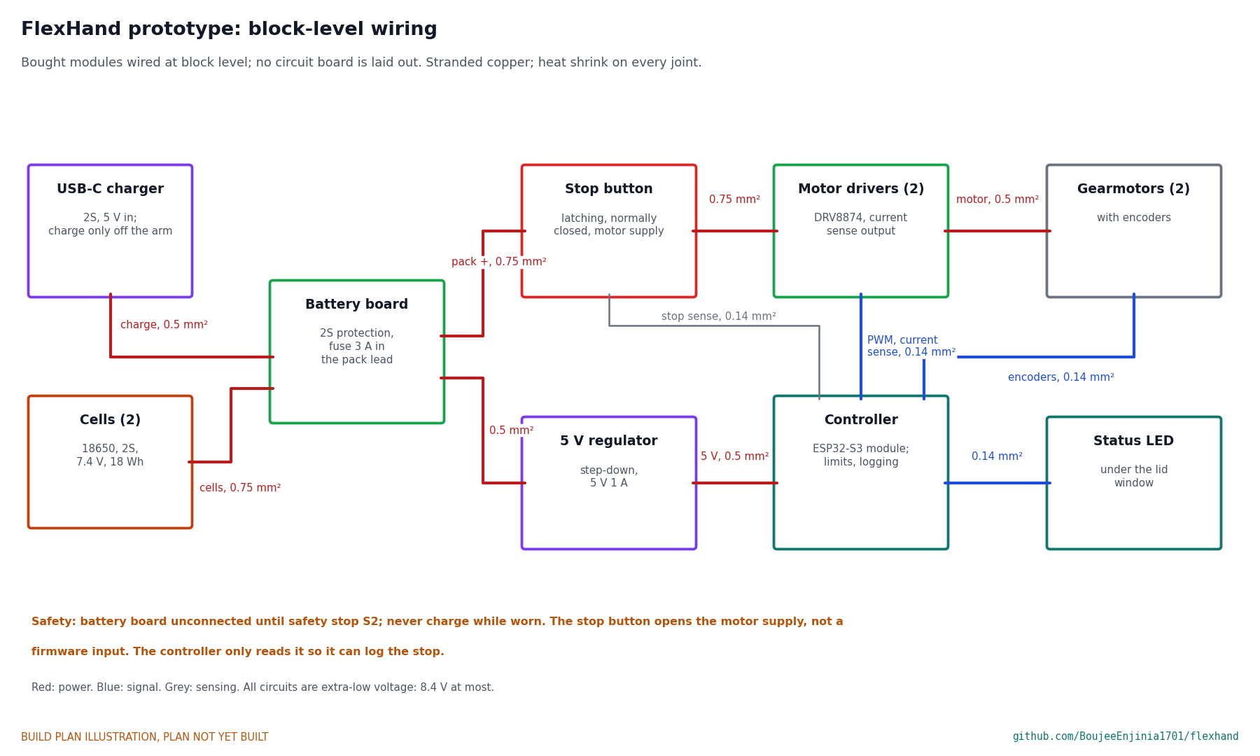
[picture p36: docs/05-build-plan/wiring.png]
Figure 16. Block-level wiring


*Figure 16. Block-level wiring with wire sizes. No circuit board is laid out at this stage.*

**How it fits the parts next to it.** It rests on the four posts in the rear bay, 1 mm over the cells with a 1 mm foam pad between, and four M2.2 x 8 self-tapping screws hold it (Figure 6). The charger's port lines up with the opening in the rear wall.

**Check before moving on.** Every wire continues end to end; with the cells out, the battery board's pack terminals read open to every other rail.

### 3.8 Pack lid

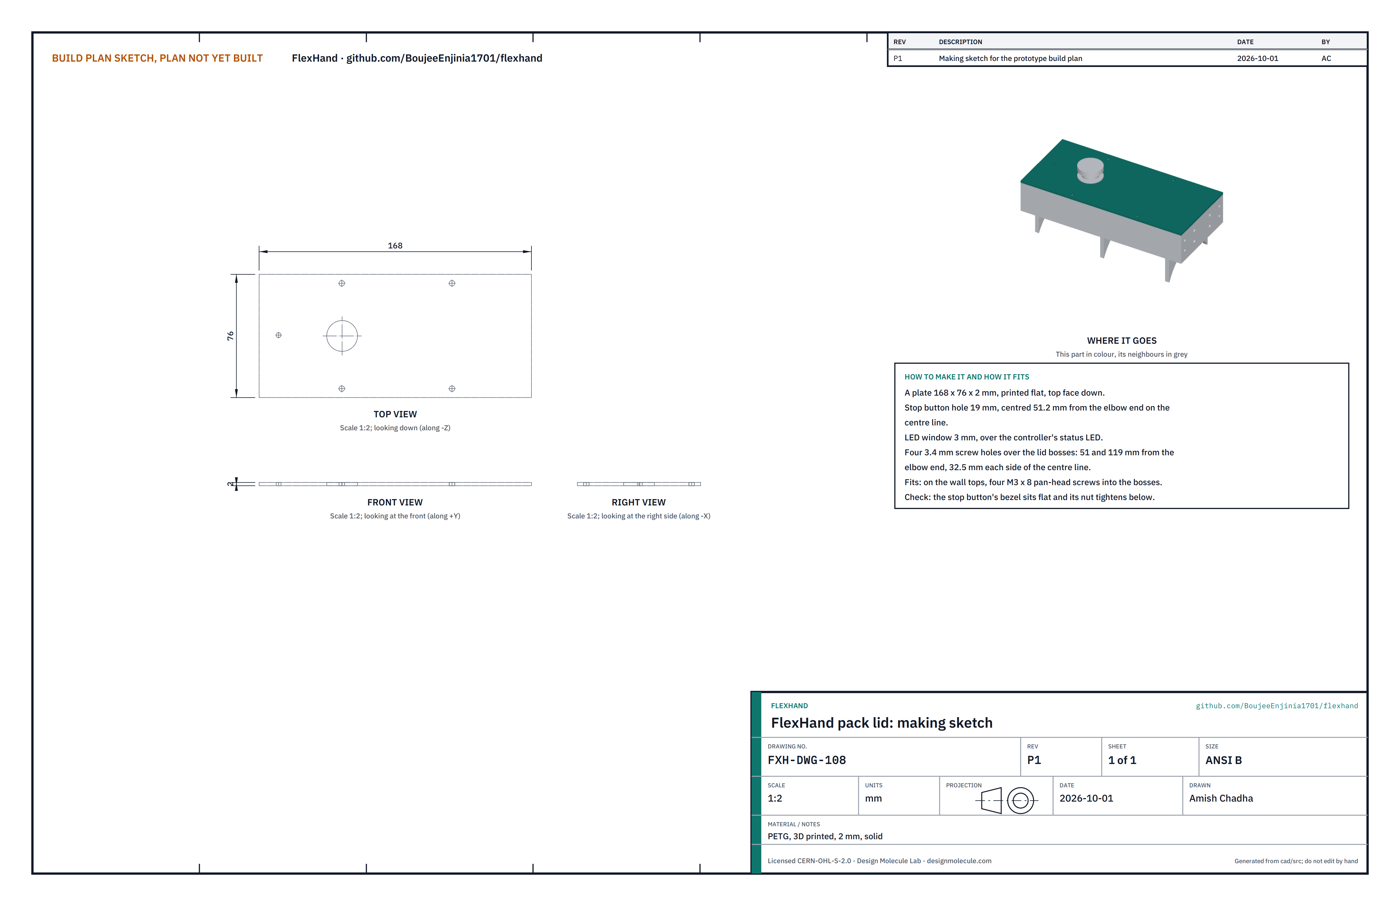
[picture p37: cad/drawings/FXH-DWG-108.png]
Figure 17. Making sketch of the pack lid


*Figure 17. Pack lid making sketch (FXH-DWG-108).*

**What it is and what it is made from.** The cover over the pack, carrying the stop button. PETG, printed, 2 mm, solid.

**How to make it.**

1. Print it flat, 168 by 76 by 2, top face down.
2. Check the 19 mm stop button hole on the centre line, 51.2 from the elbow end, the 3 mm LED window over the controller, and the four 3.4 mm screw holes, 51 and 119 from the elbow end, 32.5 to each side of the centre line.

**How it fits the parts next to it.** On the wall tops; four aluminium M3 x 8 pan-head screws into the lid bosses, tightened only until snug because aluminium threads strip easily. The stop button goes through it from above, its bezel on the lid and its nut below.

**Check before moving on.** The stop button's nut tightens with the bezel flat on the lid.

### 3.9 Dorsal plate

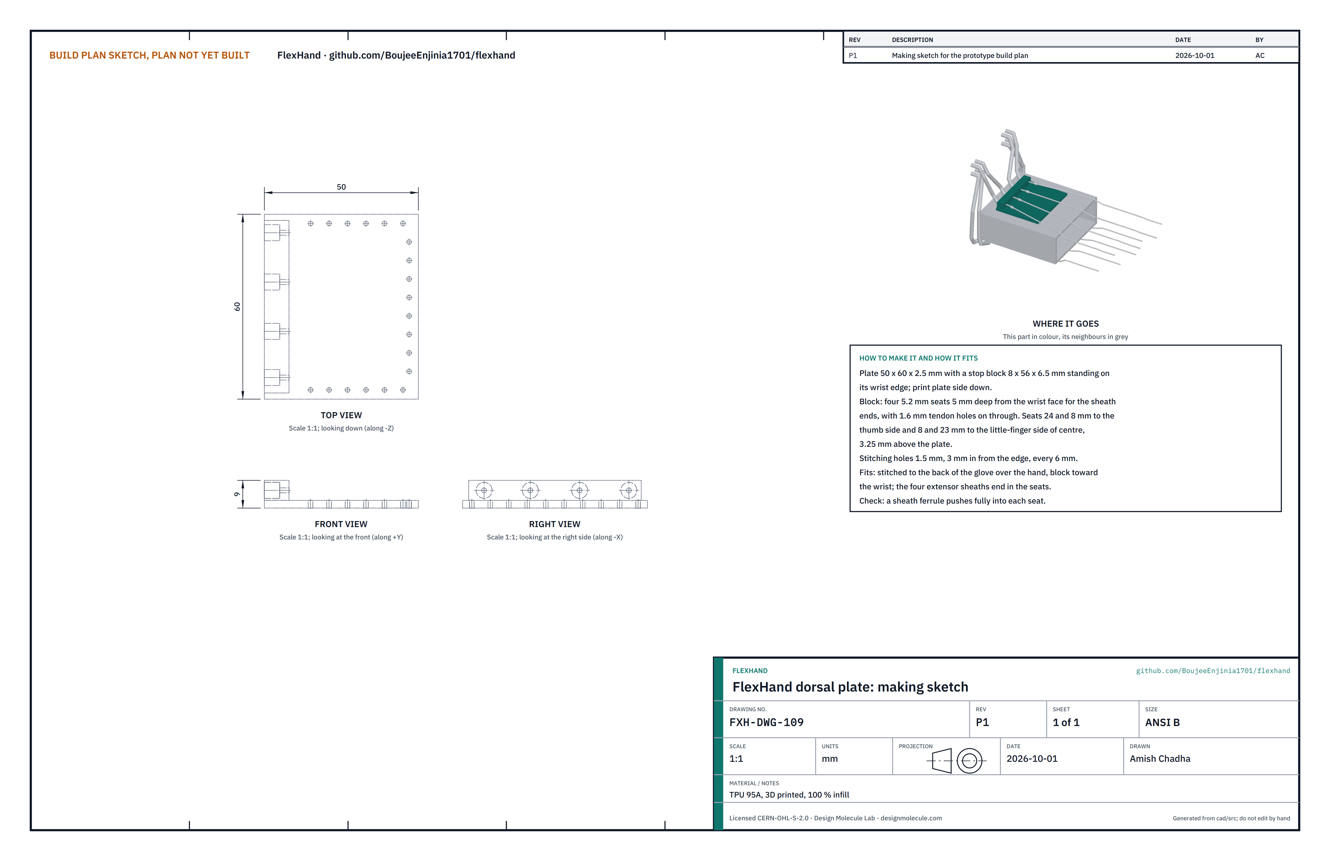
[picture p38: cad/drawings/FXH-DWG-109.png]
Figure 18. Making sketch of the dorsal plate


*Figure 18. Dorsal plate making sketch (FXH-DWG-109).*

**What it is and what it is made from.** The plate on the back of the hand where the four extensor sheaths end. TPU 95A, printed, 100 % infill.

**How to make it.**

1. Print it plate side down: 50 by 60 by 2.5, with a stop block 8 by 56 by 6.5 on its wrist edge.
2. Check the four 5.2 mm seats, 5 deep from the block's wrist face, and the 1.6 mm tendon holes on through. The seats are 24 and 8 to the thumb side and 8 and 23 to the little-finger side of centre, 3.25 above the plate.
3. Check the 1.5 mm stitching holes, 3 in from the edge, every 6.

**How it fits the parts next to it.**

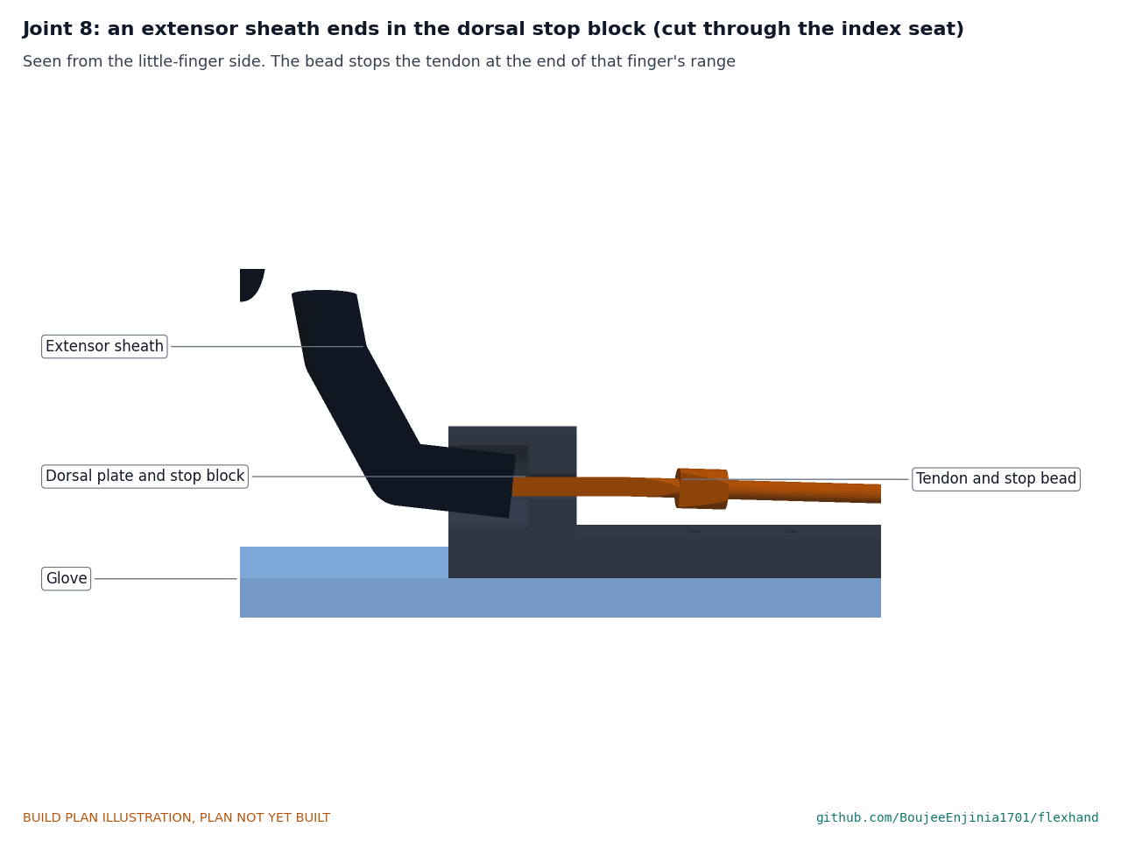
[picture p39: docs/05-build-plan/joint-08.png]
Figure 19. Joint 8: extensor sheath in the dorsal stop block


*Figure 19. The sheath's ferrule sits in its seat; the tendon goes on through to the finger. The crimped bead stops against the block at the end of that finger's range.*

Stitched to the back of the glove over the hand, block toward the wrist.

**Check before moving on.** A sheath ferrule pushes fully into each seat.

### 3.10 Palmar plate

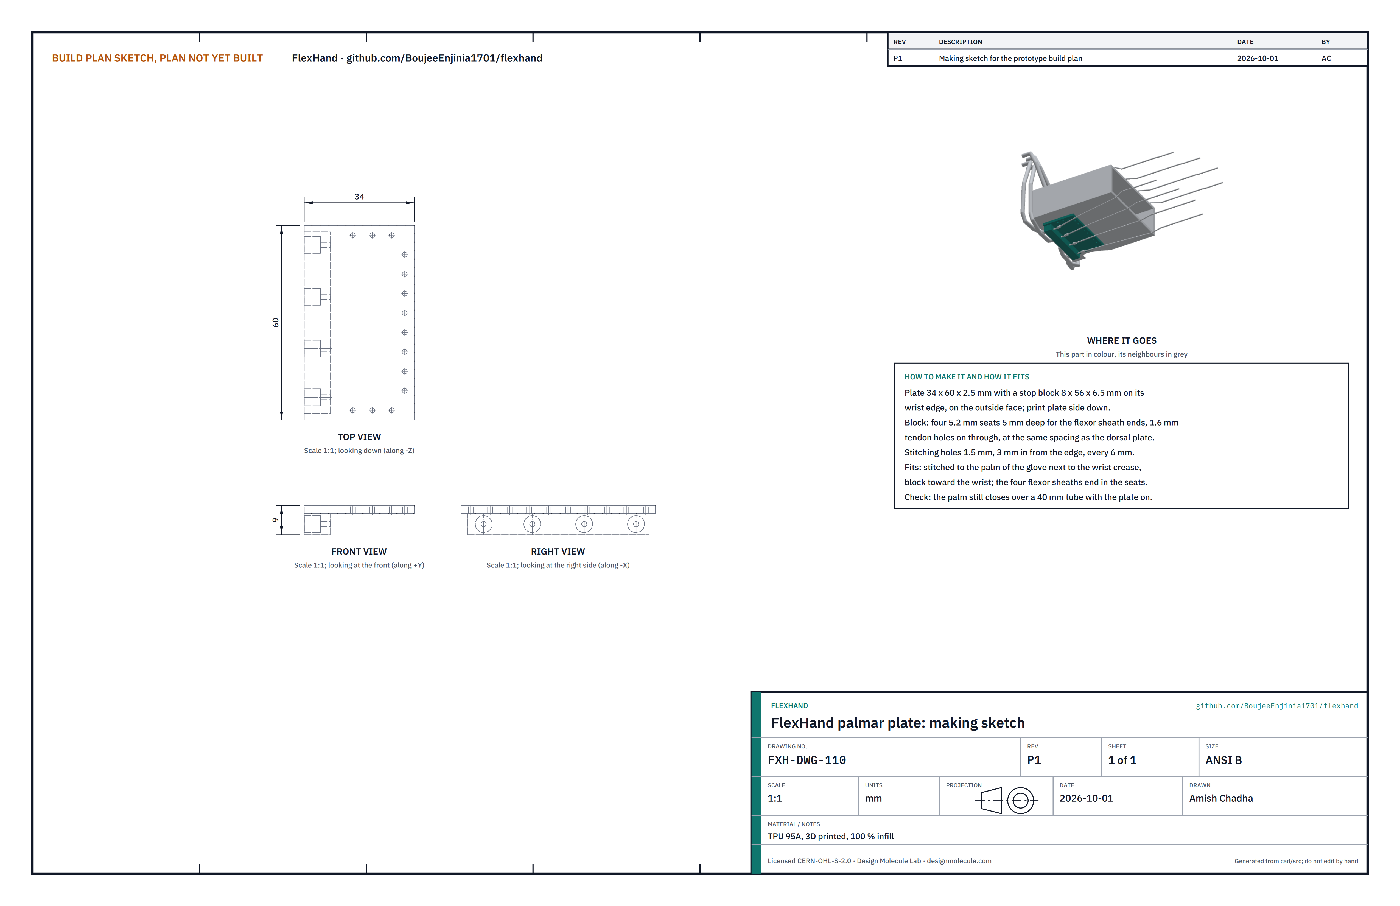
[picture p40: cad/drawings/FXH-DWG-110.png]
Figure 20. Making sketch of the palmar plate


*Figure 20. Palmar plate making sketch (FXH-DWG-110).*

**What it is and what it is made from.** The plate on the palm, next to the wrist crease, where the four flexor sheaths end. TPU 95A, printed, 100 % infill.

**How to make it.**

1. Print it plate side down: 34 by 60 by 2.5, with a stop block 8 by 56 by 6.5 on its wrist edge, on the outside face.
2. Check the four 5.2 mm seats and 1.6 mm tendon holes, at the same spacing as the dorsal plate, and the stitching holes.

**How it fits the parts next to it.** Stitched to the palm of the glove next to the wrist crease, block toward the wrist; the flexor sheaths end in its seats as in Figure 19.

**Check before moving on.** With the glove on a hand form, the hand still closes round a 40 mm tube.

### 3.11 Thumb spacer

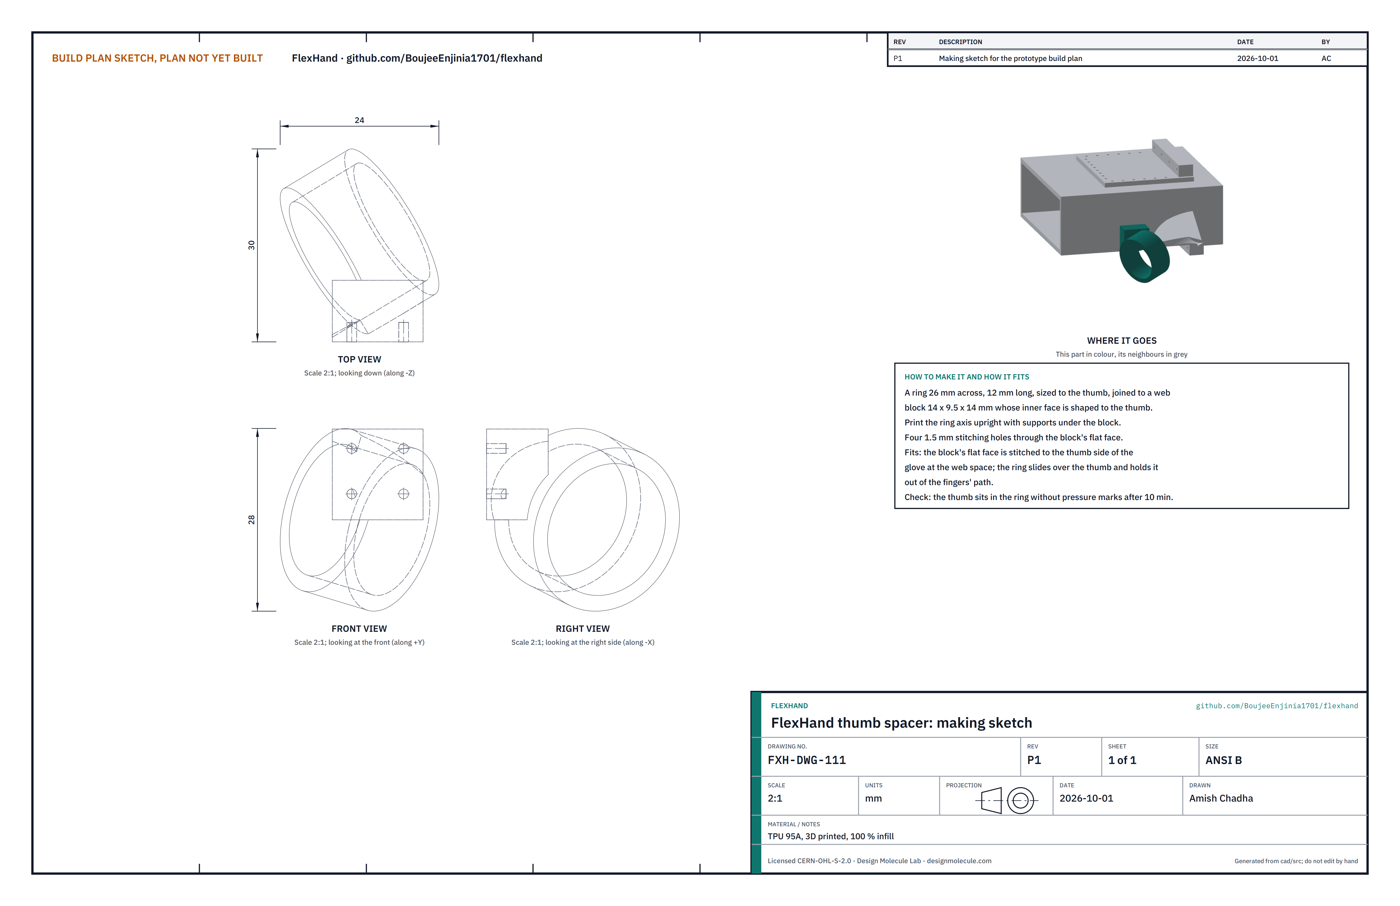
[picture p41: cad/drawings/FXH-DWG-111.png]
Figure 21. Making sketch of the thumb spacer


*Figure 21. Thumb spacer making sketch (FXH-DWG-111).*

**What it is and what it is made from.** A ring on the thumb joined to a block in the web space, which holds the thumb out of the fingers' path. TPU 95A, printed, 100 % infill.

**How to make it.**

1. Print it with the ring's axis upright and supports under the block: a ring 26 across and 12 long, and a block 14 by 9.5 by 14 whose inner face follows the thumb.
2. Check the four 1.5 mm stitching holes through the block's flat face.

**How it fits the parts next to it.**

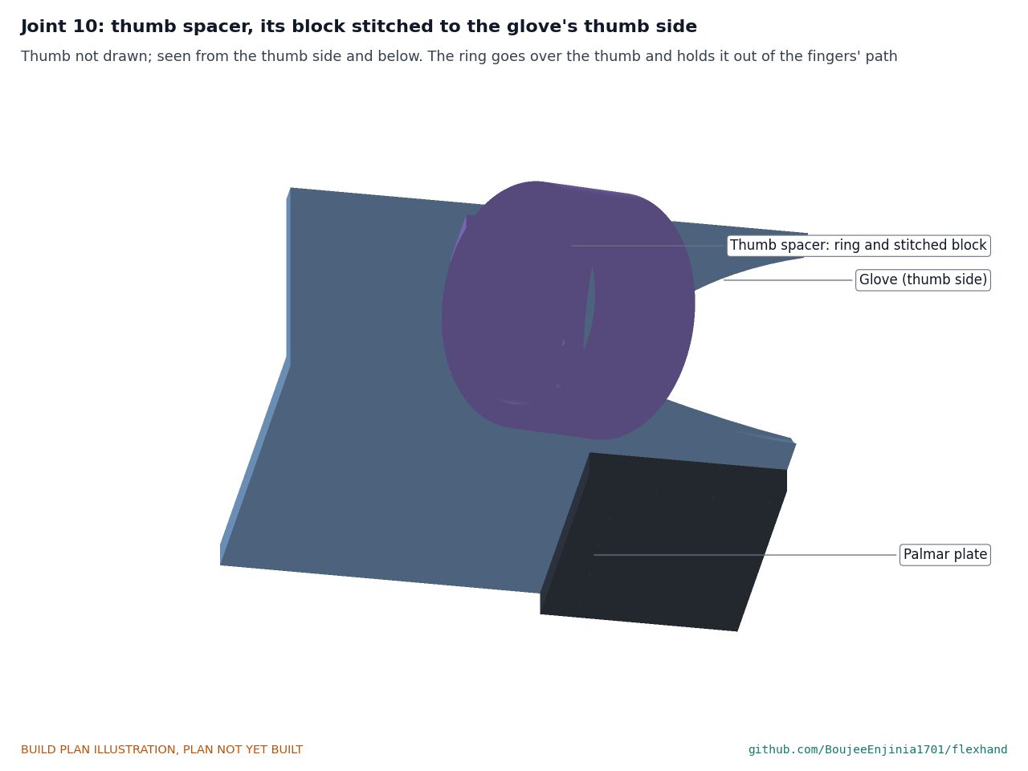
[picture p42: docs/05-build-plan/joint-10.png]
Figure 22. Joint 10: thumb spacer on the glove


*Figure 22. The block's flat face is stitched to the glove's thumb side at the web space; the ring slides over the thumb.*

**Check before moving on.** The thumb sits in the ring with no pressure marks after 10 minutes on a test hand.

### 3.12 Finger cuffs (make 8)

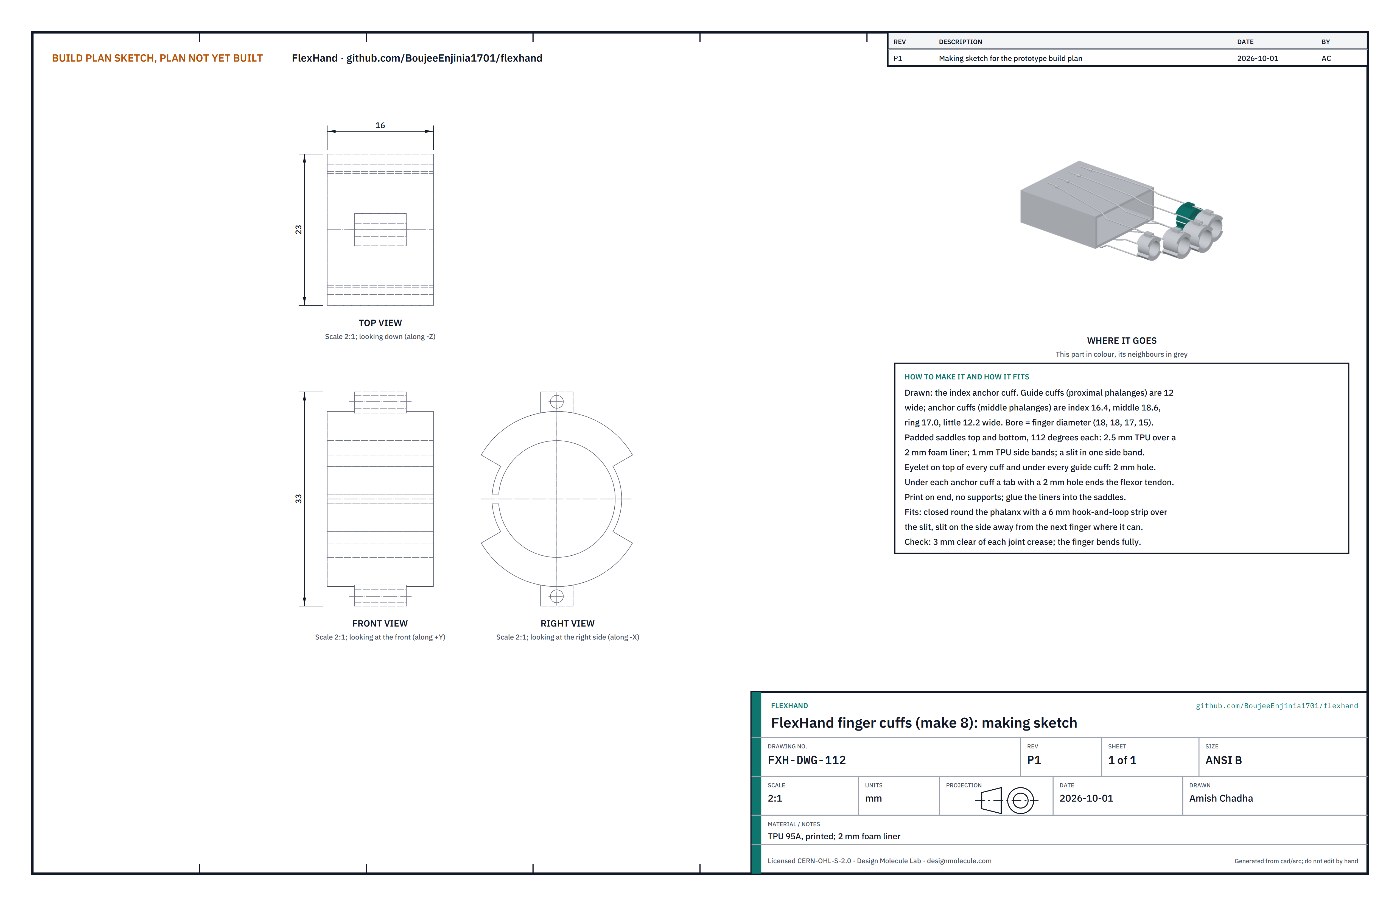
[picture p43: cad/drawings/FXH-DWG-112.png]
Figure 23. Making sketch of the finger cuff


*Figure 23. Finger cuff making sketch (FXH-DWG-112), drawn for the index anchor cuff.*

**What it is and what it is made from.** Padded bands on the fingers that the tendons pull on: a guide cuff on each first finger bone and an anchor cuff on each middle finger bone. TPU 95A, printed, with 2 mm foam liners.

**How to make it.**

1. Print each on end, no supports. Guide cuffs are 12 wide. Anchor cuffs are 16.4 (index), 18.6 (middle), 17.0 (ring) and 12.2 (little) wide. The bore is the finger's diameter: 18, 18, 17 and 15.
2. Each cuff is a padded saddle top and bottom, each covering 112° (2.5 mm of TPU outside a 2 mm liner), joined by 1 mm TPU side bands, with a slit in one side band.
3. Check the eyelets: a 2 mm hole on top of every cuff and under every guide cuff, and a tab with a 2 mm hole under every anchor cuff, where the flexor tendon ends.
4. Cut the liners from 2 mm foam and glue them into the saddles.
5. Glue a 6 mm hook-and-loop strip across each slit.

**How it fits the parts next to it.**

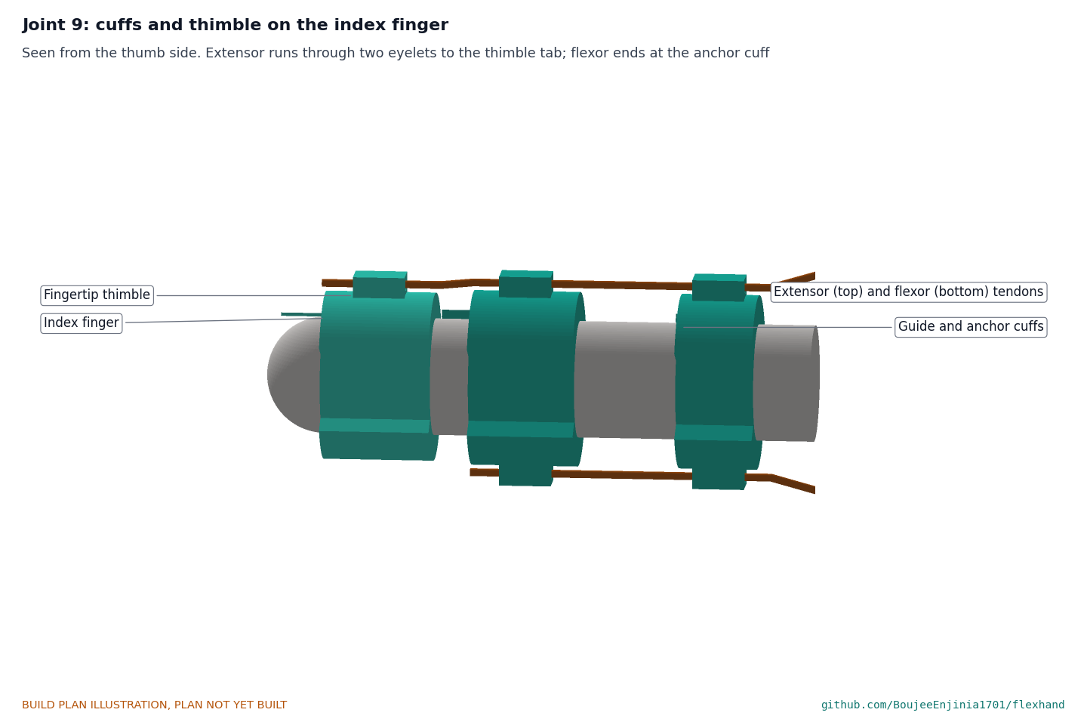
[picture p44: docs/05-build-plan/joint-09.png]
Figure 24. Joint 9: cuffs and thimble on the index finger


*Figure 24. The extensor tendon runs through the eyelets on top of both cuffs to the thimble's tab; the flexor runs through the guide cuff's lower eyelet and ends at the anchor cuff's tab.*

Each closes round its finger bone, 3 clear of each joint crease, slit on the side away from the next finger where possible. The glove holds the fingers slightly apart so neighbouring cuffs clear each other.

**Check before moving on.** On a test hand, every finger bends fully with all cuffs on, and no two cuffs touch.

### 3.13 Fingertip thimbles (make 4)

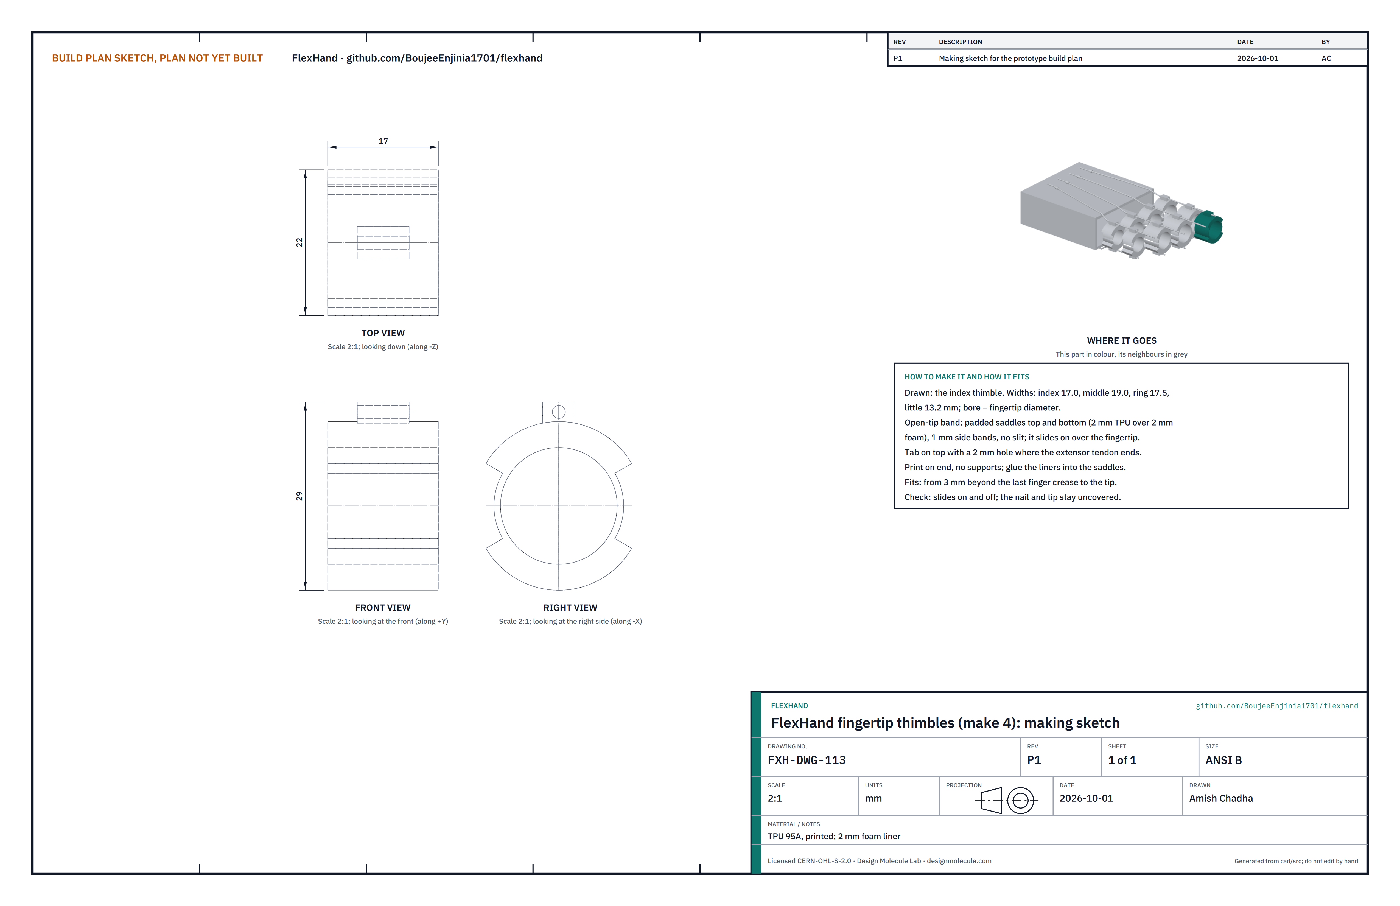
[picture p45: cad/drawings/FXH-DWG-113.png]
Figure 25. Making sketch of the fingertip thimble


*Figure 25. Fingertip thimble making sketch (FXH-DWG-113), drawn for the index finger.*

**What it is and what it is made from.** An open-tip band on each fingertip that shares the extensor pull with the anchor cuff. TPU 95A, printed, with 2 mm foam liners.

**How to make it.**

1. Print each on end, no supports: index 17.0, middle 19.0, ring 17.5 and little 13.2 wide, bore the fingertip's diameter.
2. Padded saddles top and bottom (2 mm of TPU outside a 2 mm liner) and 1 mm side bands, with no slit; a tab on top with a 2 mm hole for the end of the extensor tendon.
3. Glue in the liners.

**How it fits the parts next to it.** It slides onto the fingertip, from 3 beyond the last finger crease to the tip (Figure 24).

**Check before moving on.** It slides on and off; the nail and the tip stay uncovered.

### 3.14 Sheaths (make 8)

**What they are and what they are made from.** Eight lengths of 4 mm PTFE-lined bicycle shift housing, each with a ferrule on both ends. They carry the tendons from the anchor block to the hand plates (Figures 9, 19 and 1).

**How to make them.** Cut each length square with housing cutters, open the liner with a pin, and fit a ferrule on each end. The lengths include a fifth extra so the wrist can bend.

*Table 2. Sheath cut lengths.*

| Finger | Extensor sheath (over the back of the wrist) | Flexor sheath (down the side and under the wrist) |
| --- | --- | --- |
| Index | 77 | 145 |
| Middle | 82 | 164 |
| Ring | 82 | 164 |
| Little | 78 | 146 |

**How they fit the parts next to them.** The anchor end sits in a puck behind the cover (Figure 9); the hand end sits in its seat in a stop block (Figure 19). The index and little flexor sheaths go down the side of the wrist first and pass under it at the stop height; the middle and ring flexor sheaths go down nearer the hand and pass under them, deeper, so no two sheaths touch.

**Check before moving on.** Each tendon slides through its sheath freely by hand.

### 3.15 Sheath pucks (make 4)

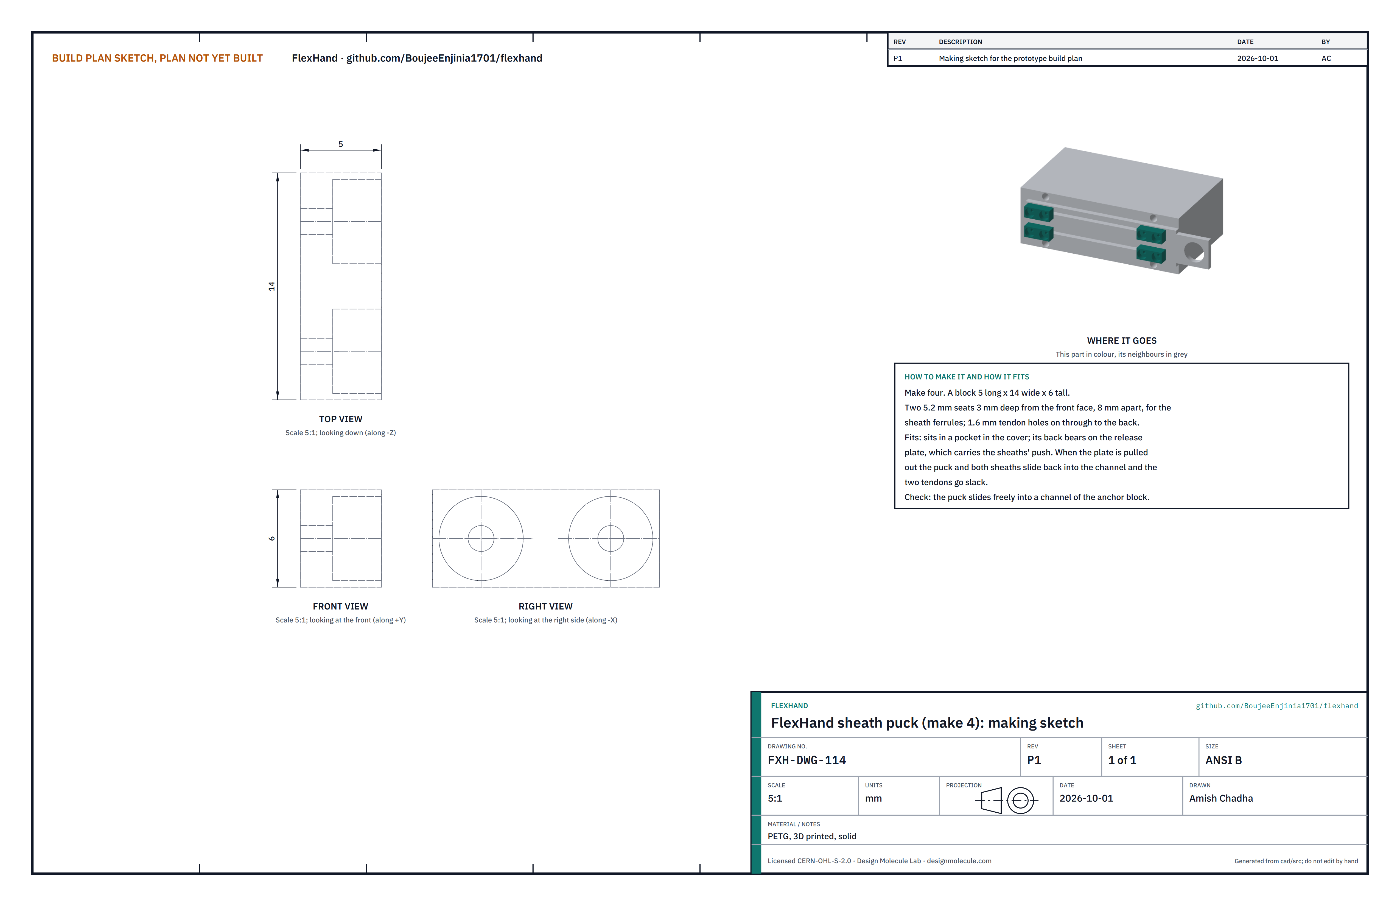
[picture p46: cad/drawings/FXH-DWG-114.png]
Figure 26. Making sketch of the sheath puck


*Figure 26. Sheath puck making sketch (FXH-DWG-114).*

**What it is and what it is made from.** A small block that holds the anchor ends of two sheaths. PETG, printed, solid.

**How to make it.** Print four, 5 long by 14 wide by 6 tall, each with two 5.2 mm seats 3 deep in the front face, 8 apart, and 1.6 mm tendon holes on through to the back.

**How it fits the parts next to it.** It sits in a pocket in the cover, and its back presses on the release plate, which carries the sheaths' push. When the plate is pulled out, the puck and both sheaths slide back into the channel and both tendons go slack (Figure 9).

**Check before moving on.** The puck slides freely into a channel of the anchor block.

### 3.16 Release plate

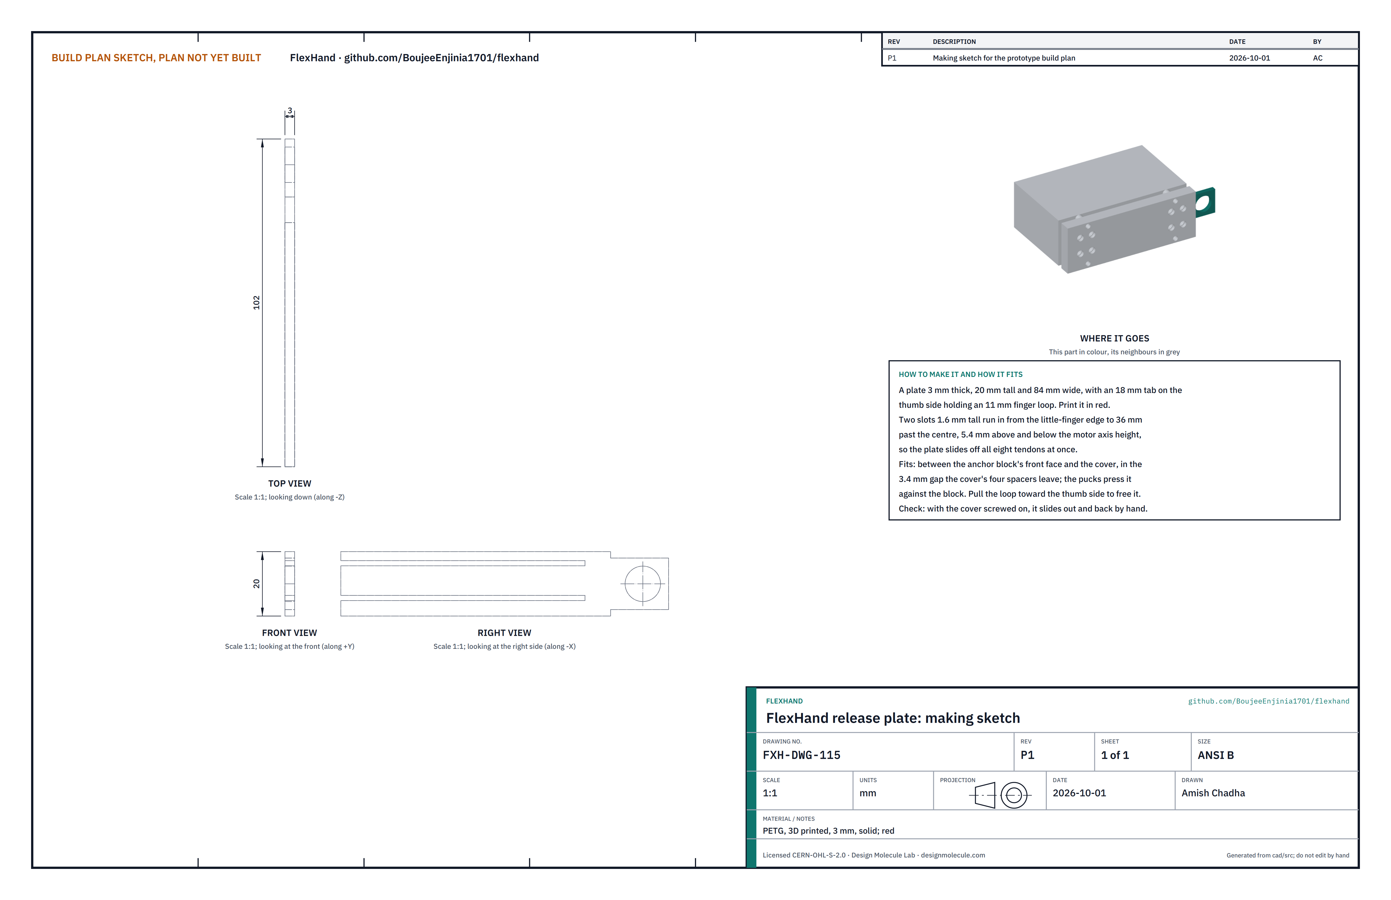
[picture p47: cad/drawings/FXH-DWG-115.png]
Figure 27. Making sketch of the release plate


*Figure 27. Release plate making sketch (FXH-DWG-115).*

**What it is and what it is made from.** The plate that, pulled out by its loop, frees all eight sheaths at once. PETG, printed, 3 mm, solid, in red so it is easy to find.

**How to make it.**

1. Print it flat: 84 wide and 20 tall, with an 18 mm tab on the thumb side holding an 11 mm finger loop.
2. Check the two 1.6 mm slots, which run in from the little-finger edge to 36 past the centre, at the two tendon heights, so the plate slides off all eight tendons.

**How it fits the parts next to it.** It slides in the 3.4 gap between the anchor block's front face and the cover; the pucks press it against the block. To release, pull the loop toward the thumb side (Figure 9).

**Check before moving on.** With the cover screwed on and no tendons fitted, it slides out and back by hand.

### 3.17 Cover

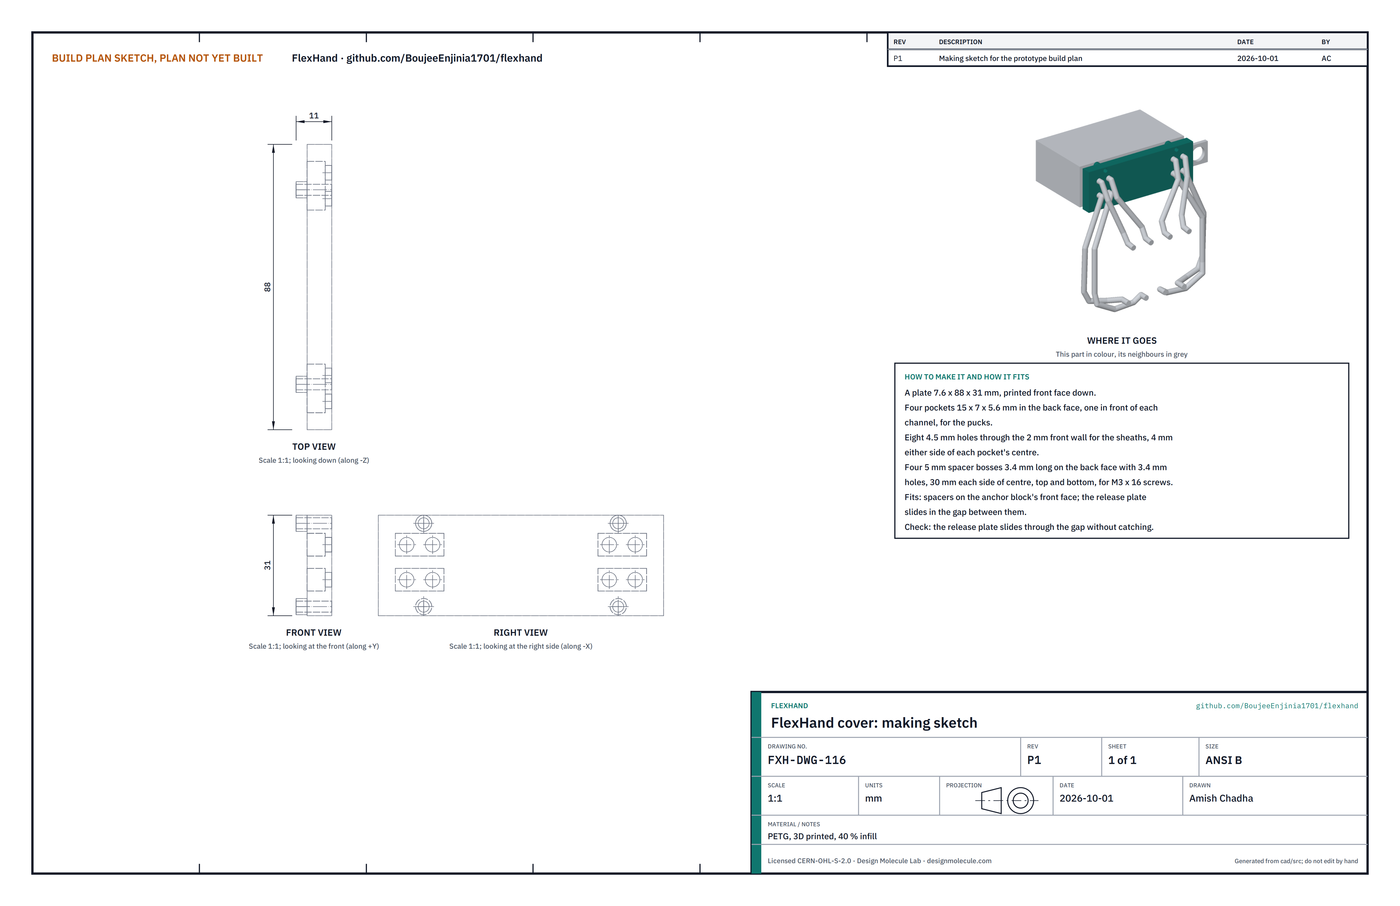
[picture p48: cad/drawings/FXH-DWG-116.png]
Figure 28. Making sketch of the cover


*Figure 28. Cover making sketch (FXH-DWG-116).*

**What it is and what it is made from.** The front of the anchor block, holding the pucks and guiding the sheaths. PETG, printed, 40 % infill.

**How to make it.**

1. Print it front face down: 7.6 by 88 by 31.
2. Check the four pockets, 15 by 7 by 5.6, in the back face in front of each channel; the eight 4.5 mm sheath holes through the 2 mm front wall, 4 either side of each pocket's centre; and the four 5 mm spacer bosses, 3.4 long, with 3.4 mm screw holes, 30 to each side of centre at top and bottom.

**How it fits the parts next to it.** Its spacers sit on the anchor block's front face, held by four aluminium M3 x 16 cap screws into the block's front inserts, tightened only until snug; the release plate slides in the gap between them (Figure 9).

**Check before moving on.** The release plate slides through the gap without catching.

### 3.18 Bought components

Buy to specification, not brand. Line numbers are those of the bill of materials.

- **Gearmotors (line 3).** Two 25 mm diameter, 71 mm long, 227:1 metal gearmotors rated 12 V with 48 counts-per-revolution encoders, 4 mm D-shaft, two M3 holes in the gearbox face.
- **Cells (line 5).** Two 18650 lithium-ion cells of 2,500 mAh from a maker that publishes a datasheet, and a 2S protection board rated 3 A or more.
- **Controller (line 6).** ESP32-S3 module of the small carrier type (about 18 by 21 mm).
- **Motor drivers (line 7).** Two single H-bridge carriers with a current-sense output (DRV8874 class).
- **Stop button (line 9).** 16 mm latching mushroom switch, normally closed, with bezel and panel nut, about 18 mm deep.
- **Sheath housing (line 11).** 2 m of 4 mm PTFE-lined shift housing and 16 ferrules.
- **Glove (line 12).** Fingerless, breathable, sizes S, M and L; it must leave the palm mostly open.
- **Tendon line (line 16).** 0.8 mm braided UHMWPE line.
- **Charger (line 18).** 2S lithium-ion charger module with USB-C input.
- **Idler and pulley bearings (lines 20 and 22).** Four 623 bearings (3 by 10 by 4) and four 693 bearings (3 by 8 by 4).
- **Fixing kit (line 24).** 18 brass M3 heat-set inserts 5 mm long; six M3 x 8 button-head, four M3 x 6 countersunk, four aluminium M3 x 8 pan-head, four M3 x 8 cap and four aluminium M3 x 16 cap screws; four M2.2 x 8 self-tapping screws; eight 3 mm steel pins (four 8 long, four 6.5 long); cable ties.
- **5 V regulator (line 25).** Step-down module, 6 to 9 V in, 5 V 1 A out.
- **Straps and consumables (lines 1 and 19).** Two 38 mm hook-and-loop straps, 6 mm hook-and-loop strip, foam tape, a 1 mm foam pad, a 100 µF capacitor, wire, heat shrink, crimp sleeves for the stop beads, strong polyester thread.

## 4. Putting it together

In each picture the parts already fitted are grey and the parts being fitted are in colour, with an arrow showing the way they go in.

### Step 1: inserts into the pack base and anchor block

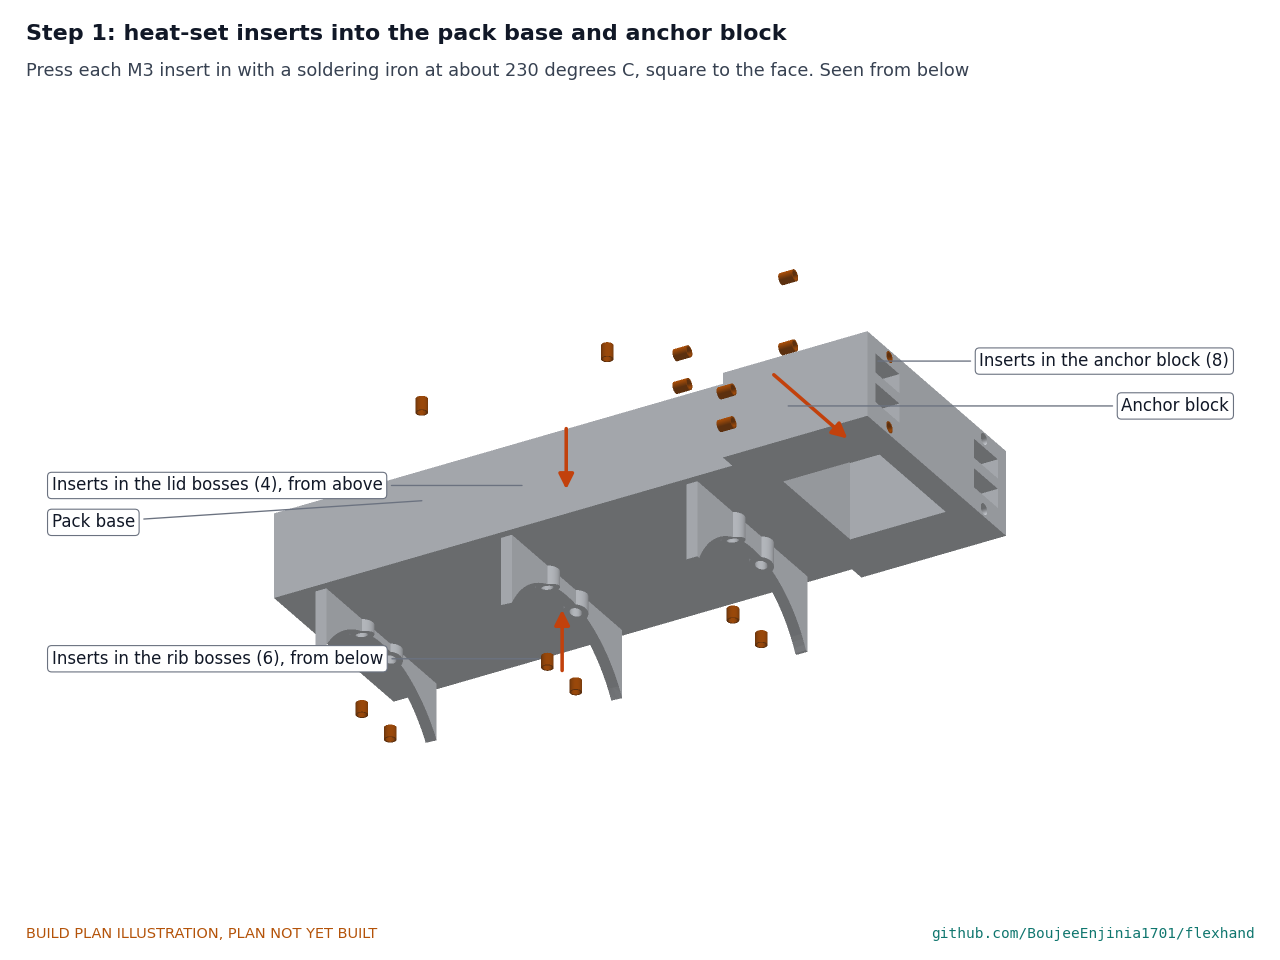
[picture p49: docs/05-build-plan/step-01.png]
Step 1


Ten inserts in the base and eight in the block, pressed in square with the iron (sections 3.1 and 3.2).

### Step 2: anchor block onto the pack

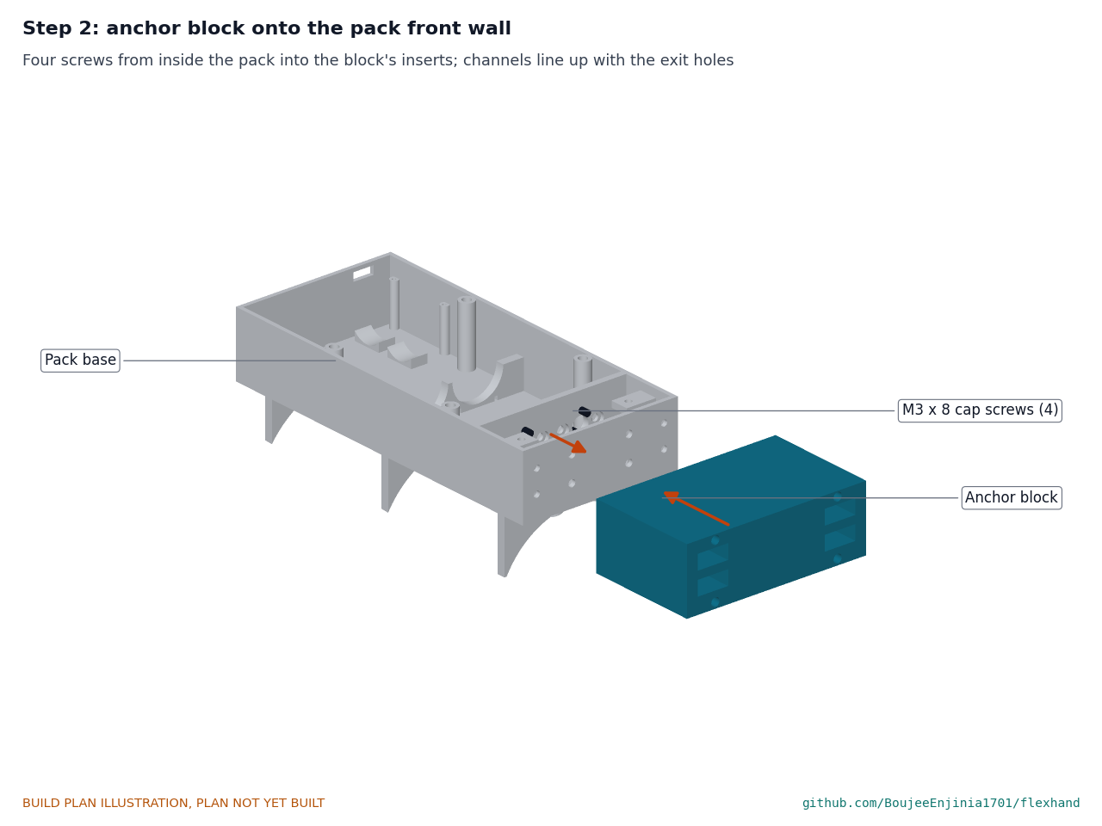
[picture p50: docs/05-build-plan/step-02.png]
Step 2


Four M3 x 8 cap screws from inside the pack into the block's back inserts, snug. Check the exit holes line up with the channels.

### Step 3: pack onto the cuff shell

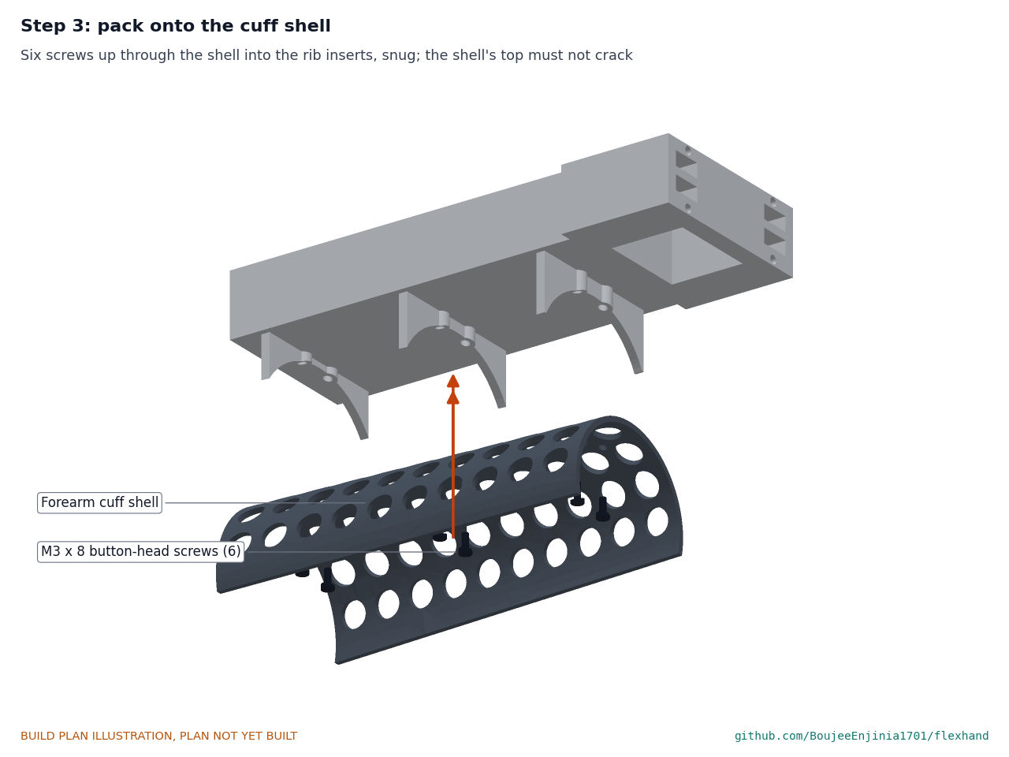
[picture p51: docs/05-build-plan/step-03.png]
Step 3


Six M3 x 8 button-head screws up through the shell into the rib inserts, snug only: the shell must not crack.

### Step 4: liner and straps

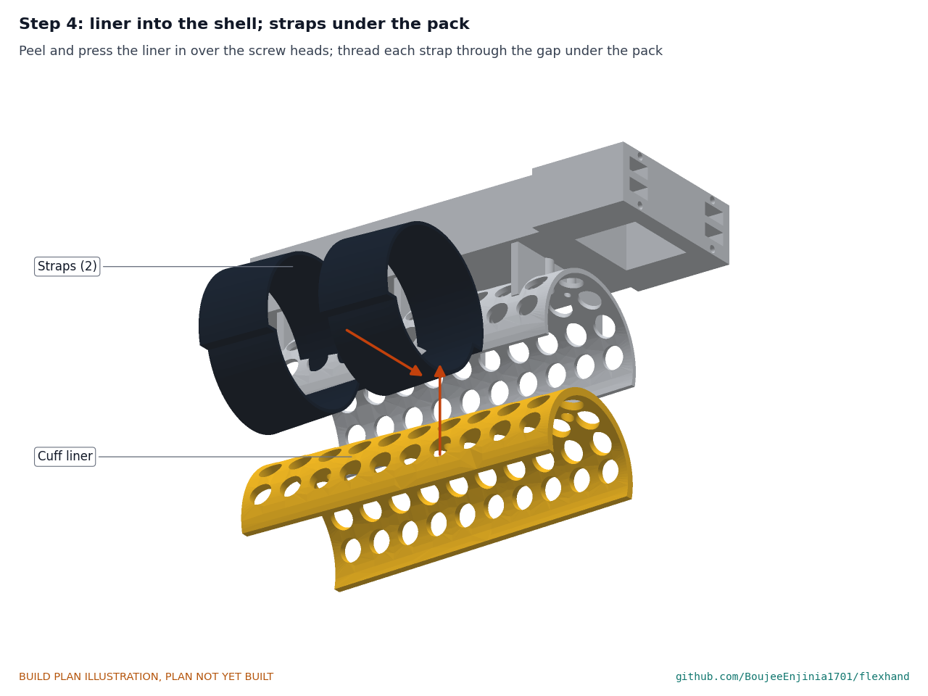
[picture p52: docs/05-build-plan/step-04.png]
Step 4


Stick the liner in over the screw heads and punch its holes (section 3.4). Thread each strap through the gap under the pack between two ribs.

### Step 5: gearmotors

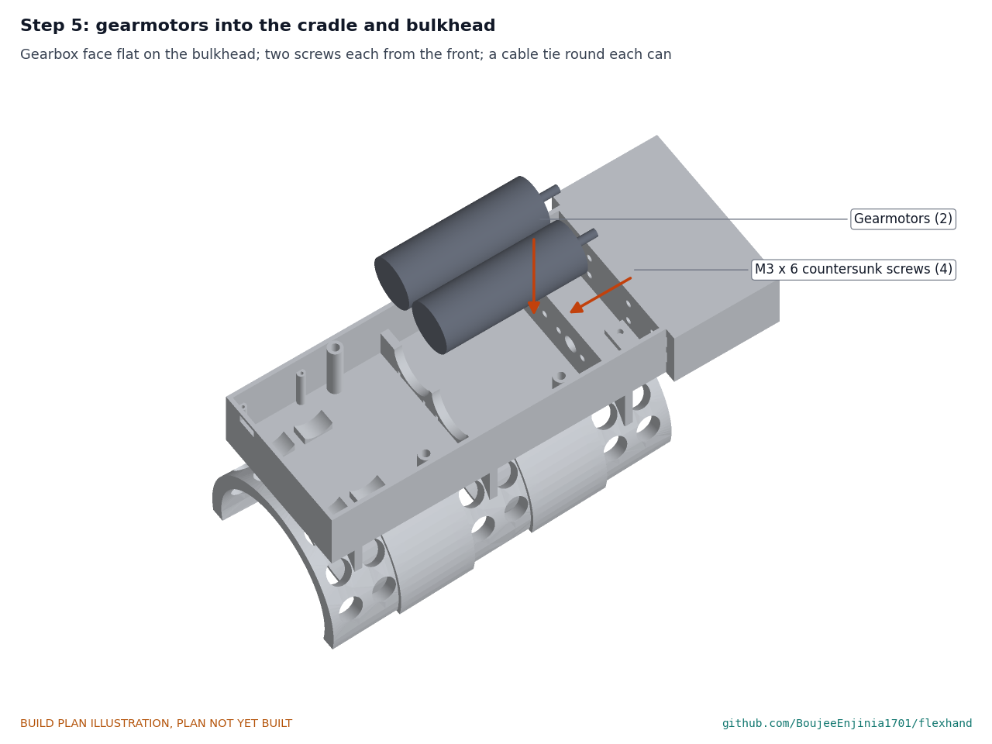
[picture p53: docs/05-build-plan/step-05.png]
Step 5


Each gearbox face flat on the back of the bulkhead, two M3 x 6 countersunk screws from the front. The screws must not be longer than 6 mm, or they can reach the gears. A cable tie through the cradle slots round each motor.

### Step 6: spools

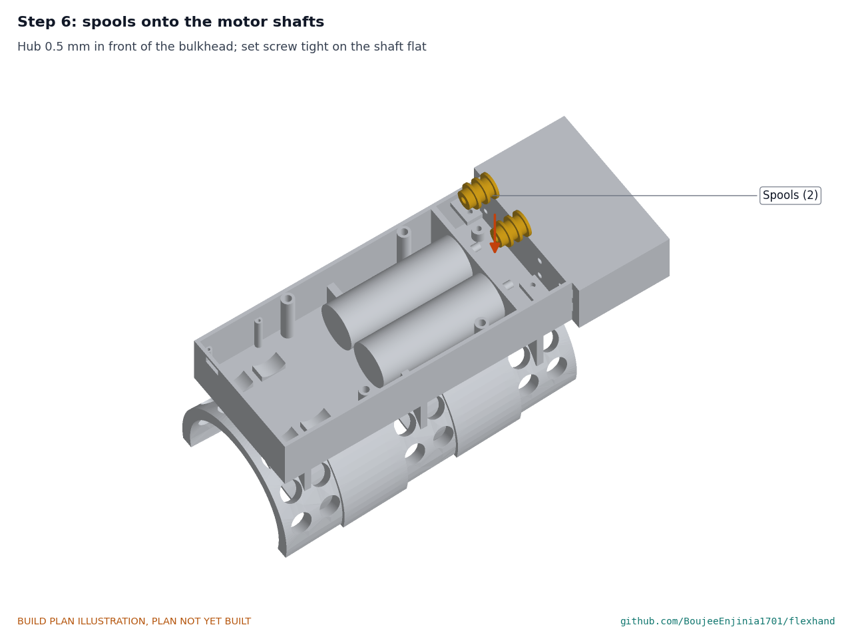
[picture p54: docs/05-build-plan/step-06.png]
Step 6


Each spool onto its shaft, hub 0.5 from the bulkhead, set screw tight on the flat.

### Step 7: idlers

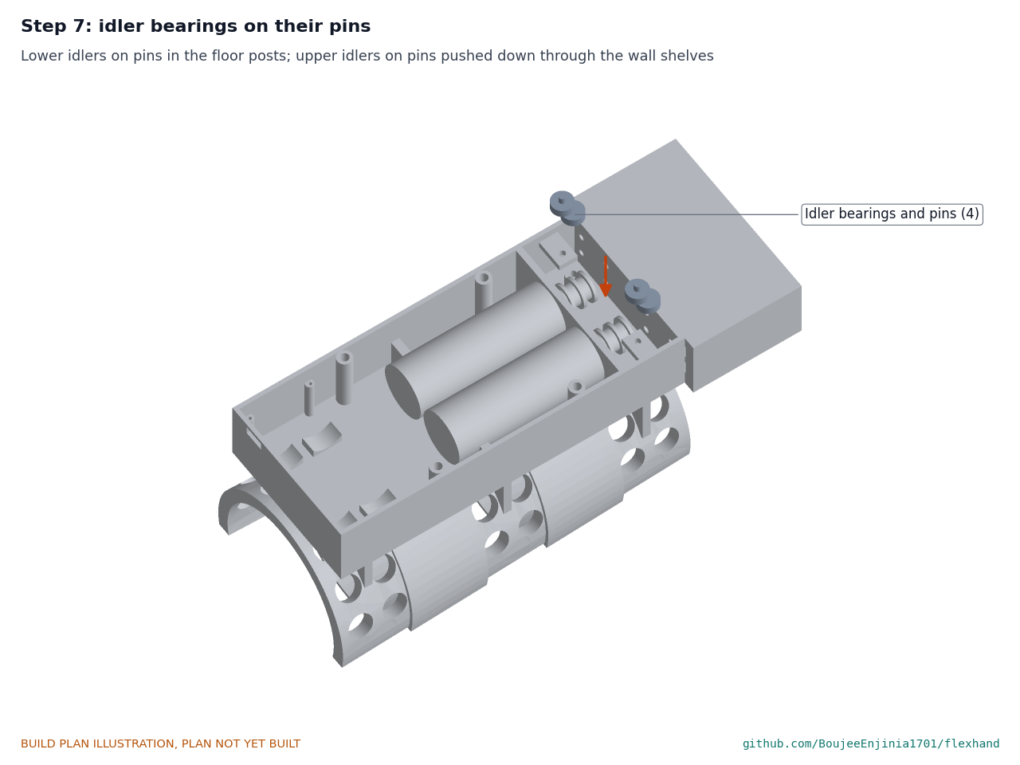
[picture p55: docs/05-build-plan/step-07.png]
Step 7


Lower idlers on pins pressed into the floor posts; upper idlers held under the shelves by pins pushed down through them. A thin washer above and below each.

### Step 8: lines, springs, pulleys and couplings

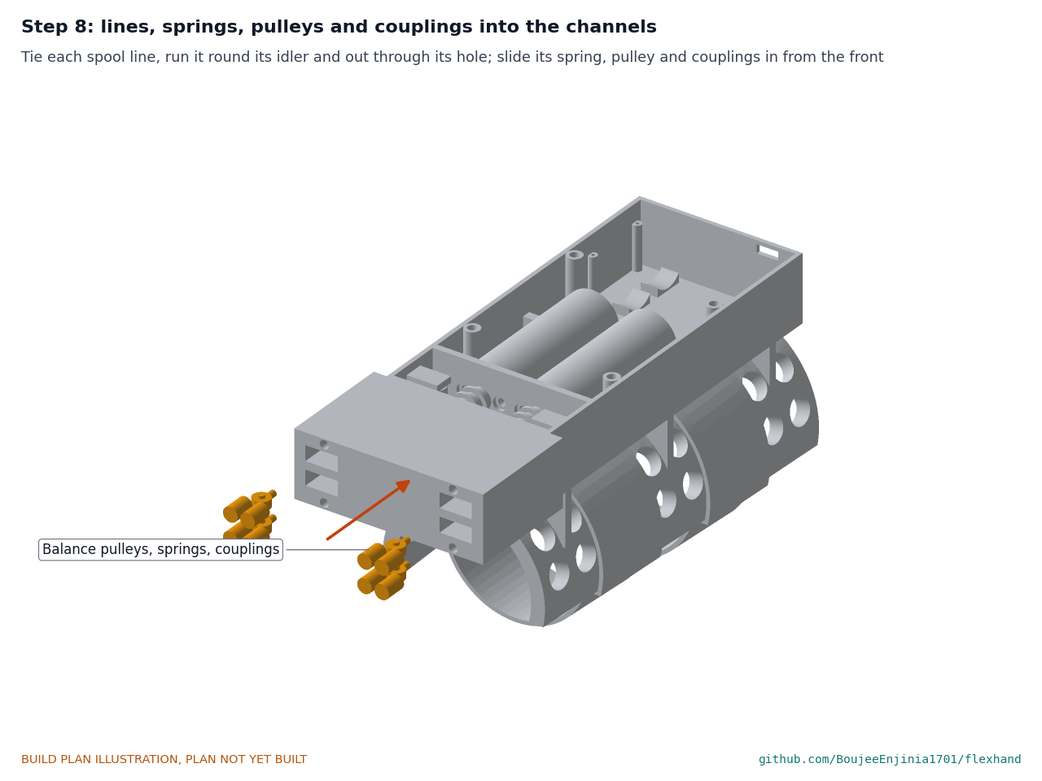
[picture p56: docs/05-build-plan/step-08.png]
Step 8


For each of the four spool lines: tie the line through its groove's hole, wind about one turn, run it round its idler and out through its exit hole into the channel. Tie its slack spring and its balance pulley's pin to it. Run a line round the pulley and tie a coupling socket to each end, so the two sockets sit just in front of the pulley. Slide the set in from the front of the channel. Extensor lines go in the upper channels and flexor lines in the lower ones; the thumb-side channels serve the index and middle fingers.

### Step 9: cells and regulator

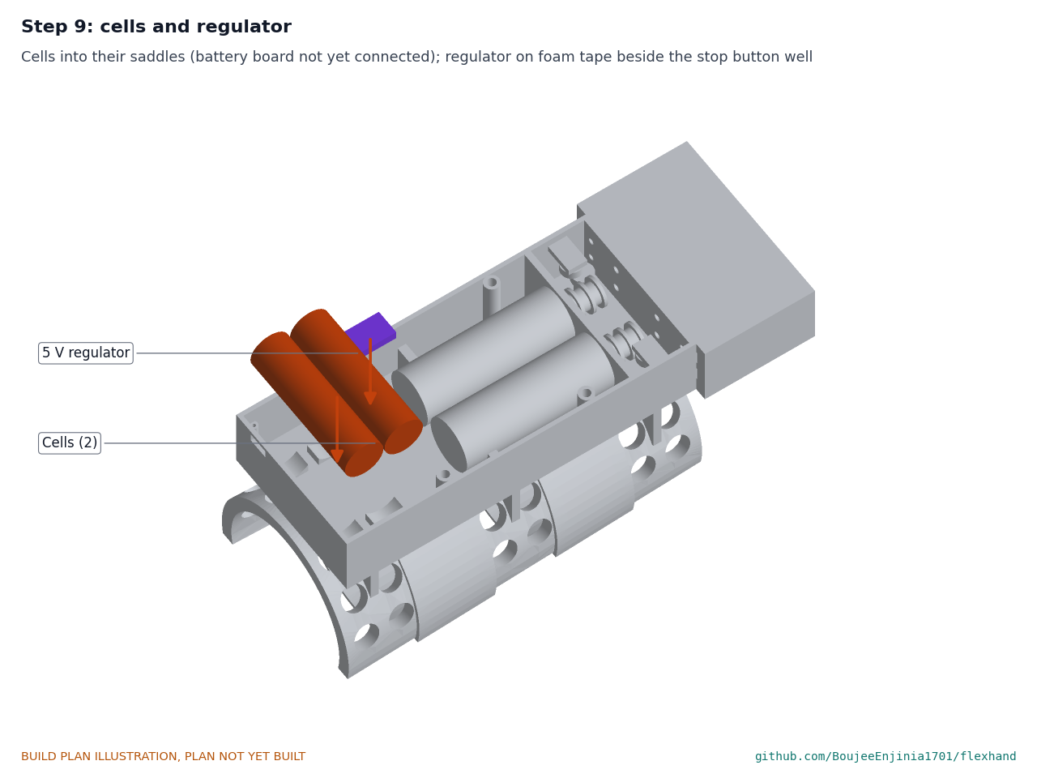
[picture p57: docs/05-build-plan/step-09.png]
Step 9


Cells into their saddles with the battery board leads free; the regulator on foam tape beside the stop button well. **Hold point:** safety stop S1.

### Step 10: tray, modules and wiring

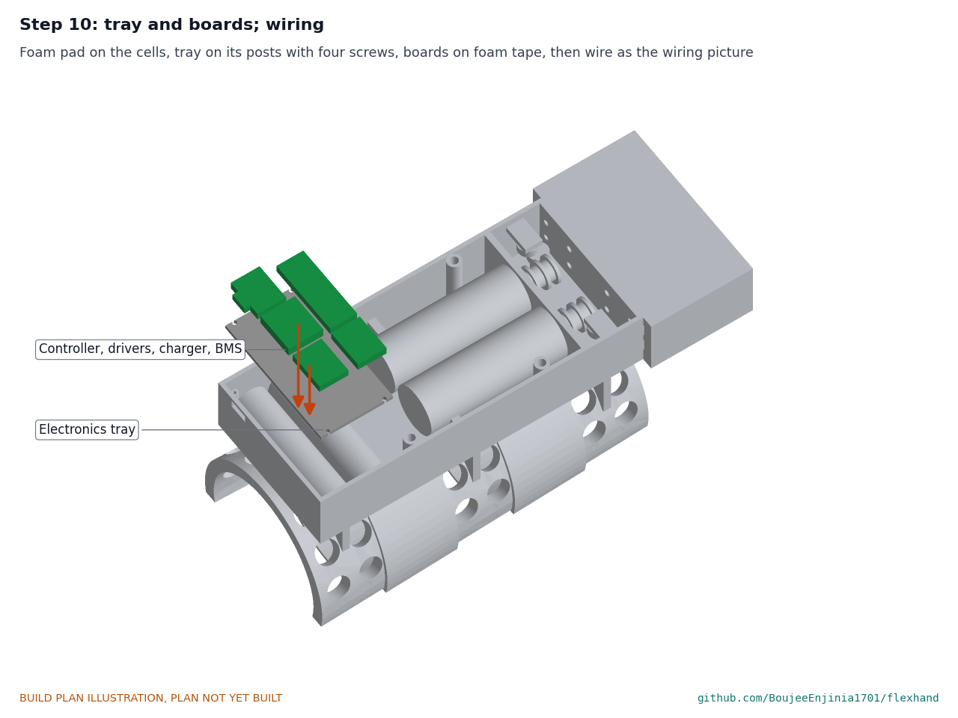
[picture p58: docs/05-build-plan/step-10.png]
Step 10


Foam pad on the cells, tray onto its posts with four screws, then finish the wiring as Figure 16, with the cell leads still unconnected. **Hold point:** safety stop S2.

### Step 11: lid and stop button

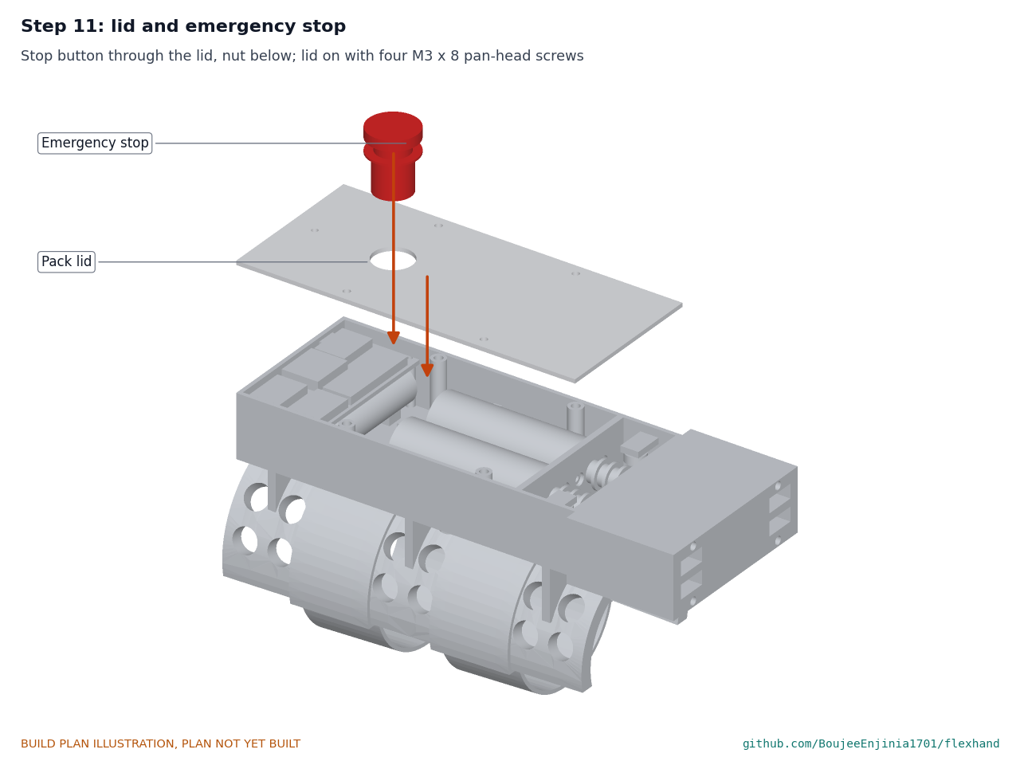
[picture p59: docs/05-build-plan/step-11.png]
Step 11


Stop button through the lid, nut below; lid on with four aluminium M3 x 8 pan-head screws, snug only.

### Step 12: plates and thumb spacer onto the glove

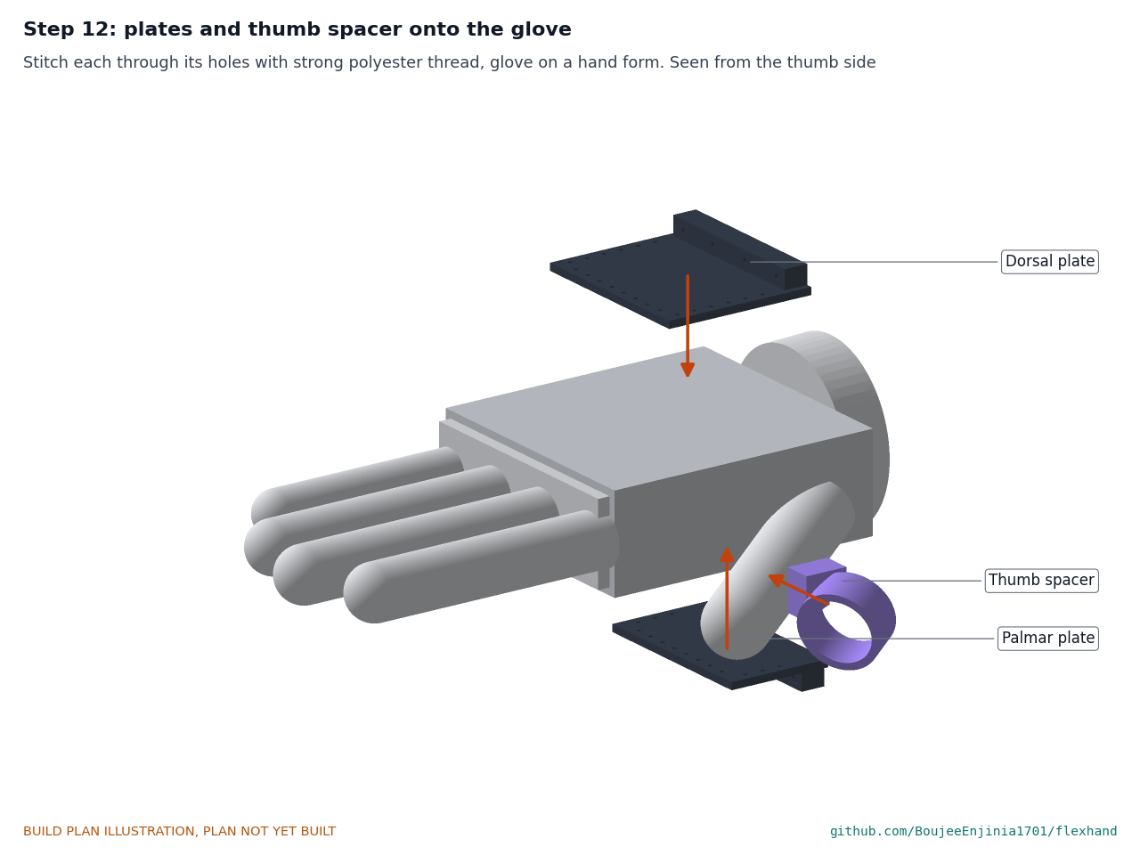
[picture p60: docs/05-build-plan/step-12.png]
Step 12


With the glove on a hand form, stitch each plate and the thumb spacer through its holes with strong polyester thread.

### Step 13: cuffs, thimbles and tendons

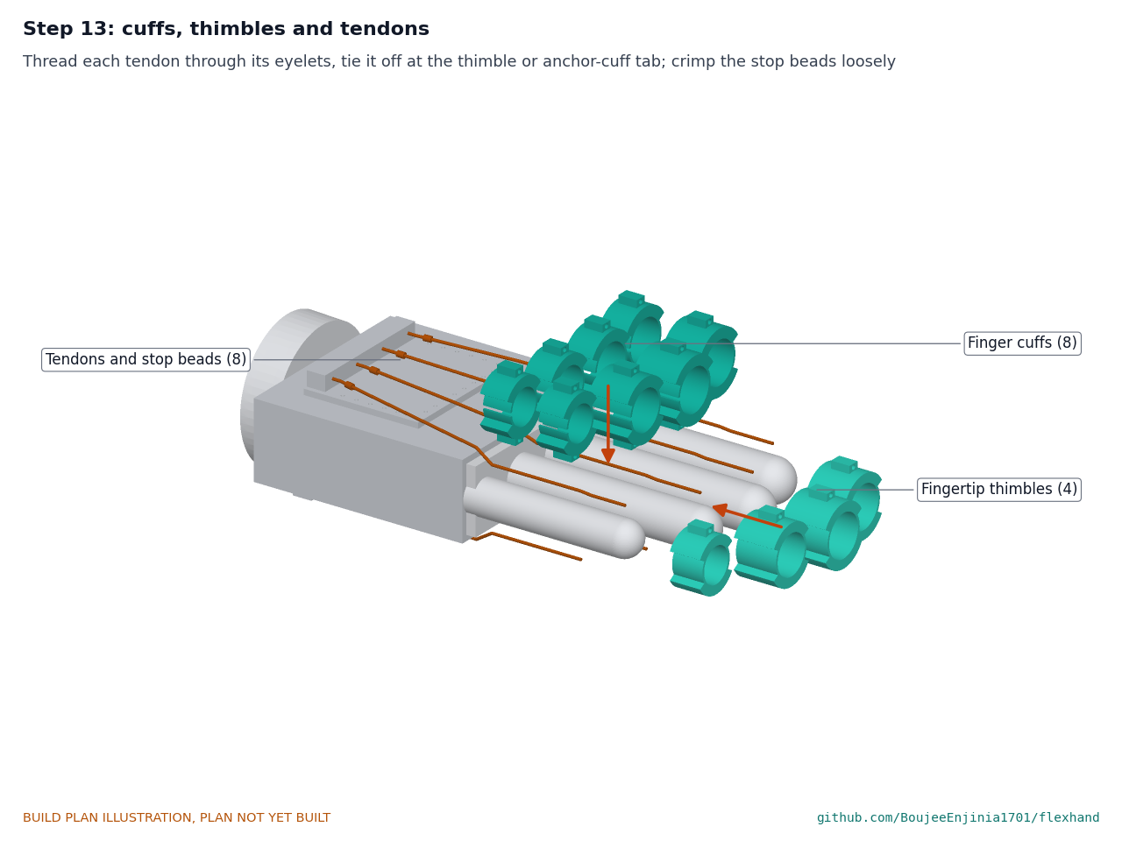
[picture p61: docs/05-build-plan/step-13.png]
Step 13


Cut eight tendons about 400 long. Thread each extensor from the dorsal stop block through the eyelets on top of its two cuffs and tie it off at its thimble's tab. Thread each flexor from the palmar stop block through its guide cuff's lower eyelet and tie it off at its anchor cuff's tab. Slide a crimp sleeve onto each tendon between the stop block and the first cuff, and leave it loose.

### Step 14: sheaths

Step 14

Slide each sheath over its tendon, hand end into its stop block seat. Extensors go over the back of the wrist, flexors down the side and under the wrist as section 3.14 describes.

### Step 15: pucks, release plate and cover

Step 15

Pass each pair of tendons through a puck, seat the sheath ends in the puck, and tie each tendon to its coupling plug; click the plugs into the sockets. Slide the release plate into place, drop the pucks into the cover's pockets, and fit the cover with four aluminium M3 x 16 cap screws, snug only. With the motors at mid-stroke and the hand form's fingers half bent, take up the slack at each coupling plug, then set each stop bead at the end of its finger's range and crimp it. **Hold point:** safety stop S4.

## 5. First checks

These are the checks a TRL 4 test report would record; this plan only lists them. Requirement numbers are those of FXH-REQ-001. All are bench checks on a hand form or finger model, not on a person.

*Table 3. First checks.*

| Check | Requirement | How | Pass when |
| --- | --- | --- | --- |
| Tendon stroke | R1 | Run each motor end to end with no load; measure the tendon travel at the hand plate | At least 29.8 mm on every tendon |
| Release | R9 | With 40 N on each finger of the finger model, pull the release plate | All eight tendons slack within 10 s, by hand, with no tools, at a pull force no higher than the one agreed with the co-design therapist before the test as one a care partner can apply with one hand; pull force recorded |
| Stop button | R9 | Press it during a stroke | Both motors stop at once; the controller logs the stop |
| Breakaway | R3 | Pull each coupling apart on a spring balance | About 60 N, the value recorded for each |
| Force limit | R3 | Block one finger of the model; raise the load on the other | The motor stops at the set current; neither finger passes 40 N |
| Stop beads | R3 | Block one finger; run a full stroke | The other finger stops at the end of its own range |
| Stroke time and dose | R4, R5 | Time 20 cycles at design load on the model | Stroke adjustable from 4 to 15 s; 300 or more cycles an hour |
| Extension force | R2 | Spring-loaded finger model at design load | 30 N reached at full extension; motor temperature recorded |
| Sessions per charge | R6 | Run cycles on the model from a full charge | 3 or more hours of cycling |
| Mass | R7 | Weigh the forearm unit and the hand parts | Hand parts 120 g or less (117 g estimated); forearm unit recorded (712 g estimated) |
| Fit | R10 | Fit the glove and cuffs to hand forms of 170, 183 and 205 mm | Every cuff 3 mm clear of each crease; no two cuffs touch |
| Cuff pressure | R11 | Pressure film under each cuff and thimble at design load on the model | Mean 50 kPa or less |
| Session log | R13 | Run a session; read the log | Time, cycles and peak current recorded; limits cannot be changed from the user controls |

## 6. Safety stops

Stop at each point. Carry on only when everything listed is true.

- **S1. Before the cells come into the workshop.** Each cell reads 3.0 to 4.1 V, with no dents, swelling or leaks, and has a datasheet from its maker. A charging spot is ready on a non-combustible surface with a fire extinguisher for electrical fires in reach.
- **S2. Before the cells are connected to the battery board.** With the cells out, the pack, motor and 5 V rails read open to each other; the battery board's cell order is checked with a meter, not by wire colour; the stop button opens the motor supply when pressed.
- **S3. Before first power.** The lid is on; the anchor block's channels have no lines in them; a current-limited bench supply at 7.4 V and 1 A stands in for the cells; the stop button cuts the motors at once.
- **S4. Before any tendon is loaded.** The release plate slides out freely; every coupling's force has been set; the force limit is set in firmware at its lowest value; the stop beads are crimped; a person who knows the release is within reach.
- **S5. Charging.** Only with the pack off any arm or form, on the charging spot, attended; stop if a cell passes 45 °C or the pack swells.
- **S6. Before anything is worn by a person (outside this plan).** Not part of this build. Wearing needs the TRL 4 bench results, a supervising therapist, informed consent and, in a research setting, ethics review, and the co-design therapist's check of the finger spread on a range of hands with mild tone (single-saddle cuffs if the spread raises tone or discomfort) and of the pack's load on a weak arm and shoulder.

## 7. Tools, skills and workspace

**Tools.** FDM 3D printer with a bed of at least 180 by 100 mm that prints PETG and TPU 95A; soldering iron with a heat-set insert tip; drills 1 to 3.4 mm in a hand drill and pin vice; M3 tap; countersink; craft knife and steel rule; 12 mm and 6.5 mm hole punches; housing cutters; crimping pliers; hex keys 1.5 to 2.5 mm; small screwdrivers; needle and strong polyester thread; spring balance to 100 N; digital calipers; multimeter; bench power supply with a current limit (0 to 15 V, 0 to 3 A); hand form or finger model.

**Skills.** No certified trade is needed. 3D printing in PETG and TPU, pressing in heat-set inserts, simple soldering and crimping, hand sewing, tying line, safe use of a bench supply and care with lithium cells. All circuits are extra-low voltage: 8.4 V at most; no mains wiring is part of this build.

**Workspace.** A bench about 1.2 by 0.6 m; a ventilated place for the printer and soldering; the charging spot of S1.

**Personal protective equipment.** Safety glasses when cutting housing and crimping; no loose sleeves or long hair near the spools while the motors run.

## 8. Where the numbers come from

- Model and constructability checks: `cad/src/model.py` (`python cad/src/model.py --check`, 203 checks); STEP and STL exports in `cad/step/` and `cad/stl/`.
- Pictures: `cad/src/build_plan_media.py`, using `.kit/build_views.py`; written to `docs/05-build-plan/` and `cad/drawings/FXH-DWG-101` to `FXH-DWG-116`.
- General arrangement: `cad/drawings/FXH-DWG-001.pdf`, Rev P3.
- Calculations: `docs/04-calcs/01-sizing.md` (FXH-CAL-001 v0.3) and `docs/04-calcs/sizing.py`; stroke [A2], force and torque [C2], speed and dose [D2], [D3], force limit and pulley travel [E1] to [E4], energy [F2], [F3], mass [G2], [G4], pressure [H2], [H3], cost [J1].
- Bill of materials: `bom/bom.csv`.
- Decisions: `docs/decisions/0003-design-for-construction.md` (FXH-DDR-003), with FXH-DDR-001 and FXH-DDR-002.
- Requirements: `docs/03-requirements.md` (FXH-REQ-001 v0.5).

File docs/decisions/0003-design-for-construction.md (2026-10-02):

---
doc_id: FXH-DDR-003
title: FlexHand design for construction
project: FlexHand
doc_type: Design decision record
version: "0.2"
status: Draft
date: '2026-10-02'
author: Amish Chadha
license: CERN-OHL-S-2.0
revisions:
- version: "0.1"
  date: '2026-10-01'
  author: Amish Chadha
  change: Changes that make the concept physically buildable, with the reason for each; made under Amish's 2026-09-30 instruction to make the design physically buildable; open for his review
- version: "0.2"
  date: '2026-10-02'
  author: Amish Chadha
  change: 'Accepted by Amish on 2026-10-02, including the recommendations for A1 to A3 with their conditions'
---

# 0003: Design for construction

- **Date:** 2026-10-01
- **Status:** accepted. Amish, 2026-10-02: "i approve your recommendations for all 555 open decisions." This covers every change in Tables 1 and 2 and the recommendations for A1 to A3 in Table 3, now decided as recommended, with the conditions below, and recorded in the design decisions register (FXH-DEC-001).

## Context

On 2026-09-30 Amish asked for every repo to get an illustrated prototype build plan and wrote: "If you are realising that the design cannot be built as per concept - fix the design assumptions to match and be physically feasible as you draw the illustrations." The concept model of FXH-DDR-002 showed what FlexHand does, and its calculations stand, but many of its parts could not be made, fitted or fixed as drawn. A build123d check of the concept model found parts that overlapped (spools and idlers, the electronics boards, the sheaths and the wrist, the finger cuffs of neighbouring fingers), parts that floated with no fixing (the pack on the cuff, the motors, the cells, the boards, the anchor block), mechanisms with no parts (the quick-release lever, the couplings, springs and stop beads in the anchor block) and one missing part (a 5 V supply for the controller).

The changes keep what FlexHand does: two gearmotors on the forearm, antagonistic spools, idlers, four floating balance pulleys, eight tendons in Bowden sheaths, eight ball-detent breakaway couplings, a hardware stop button, a tool-free release, padded cuffs and thimbles, the same motors, cells, electronics, strokes, forces, speeds and cuff contact areas. Nothing here changes the pitch. The model now runs 203 constructability checks (`python cad/src/model.py --check`): no two parts overlap, no part enters the forearm or hand, every joint touches, every clearance holds, and the release plate's path is clear. All 203 pass.

## Decision

*Table 1. Changes made to the model, the BOM and the calculations.*

| # | Problem in the concept | Change made | Why this way |
| --- | --- | --- | --- |
| C1 | The pack sat on the cuff with no fixing, and at the elbow end the cuff cut 0.7 mm into the pack floor. Two of the three saddle ribs stood over cuff holes. | The pack floor is raised 4 mm. The three ribs sit on the solid strips between hole columns (18.5, 86.5 and 154.5 mm from the cuff's elbow end), each with two screw bosses 9 mm either side of the top line. Six M3 x 8 button-head screws go up through 3.4 mm holes in the shell into heat-set inserts in the bosses. The liner has a 6.5 mm hole over each screw head and is glued in after the pack is fitted. | The pack must not move on the cuff under the sheath reaction (up to about 180 N along the forearm). Screws through the shell into printed bosses are the simplest fixing that can be undone; the strips between holes leave the perforation as it was. |
| C2 | The straps were drawn inside the liner, where they overlapped it. | Each strap lies over the shell, passes through the gap under the pack between two ribs, steps off the shell edge and wraps the skin under the forearm. Straps moved to 52.5 and 120.5 mm from the cuff's elbow end. | This is how a strap holds a half shell; the ribs keep the straps from sliding. |
| C3 | The gearmotors floated 1.5 mm above the floor with no fixing. | A 3 mm bulkhead printed in the pack base carries each gearbox face on two M3 x 6 countersunk screws; a cradle rib under the motor cans with a cable tie holds their rear ends. Motor axes moved from 15 to 13.5 mm either side of the centre line. | The gearbox face is the motor's intended mounting face; the bulkhead takes the spool torque. Moving the motors inward makes room for the idlers (C4). |
| C4 | The idlers cut into the 20 mm spool flanges and had no pins or supports; the spool had no way to grip the shaft. | Spool flanges 14 mm; a 4 mm hub with an M3 set screw (spool 16 mm long). Each idler runs on a 3 mm steel pin: the lower one in a printed post on the floor, the upper one under a printed shelf from the side wall. Each spool line leaves its idler 31.25 mm from the centre line and the pack through a 3 mm hole. | A 14 mm flange still stands 1.6 mm above the single layer of 0.8 mm line; the idlers then clear the flanges by 0.75 mm. |
| C5 | The rear bay did not fit: the battery board overlapped the controller, the cells sat 1 mm above the floor, the boards floated with nothing under them, the charger's port went through a solid wall, and the stop button sat 2 mm from the motors with no room for the encoder cable. The controller (an ESP32-S3 module) had no 5 V supply: it cannot take the 7.4 to 8.4 V pack voltage. | Cells in printed saddles; a 2 mm electronics tray (BOM line 23) on four posts, screwed down, holds the cells through a foam pad; the boards are laid out on the tray without overlap; a USB-C opening in the rear wall; the cells and stop button move toward the elbow so there is a 6 mm gap behind the motors. A 5 V step-down regulator is added (BOM line 25). | Every part now has a seat and a fixing. The regulator is the missing part the circuit needs. |
| C6 | The anchor block (44 mm) could not hold what the concept puts in it. Its 40 mm channels gave the balance pulleys 32 mm of travel but left no room for the eight couplings, eight slack springs and eight stop beads; its channels sat 6 mm inboard of the tendon exits; its sheath stops were 3 mm apart for 4 mm sheaths; and it had no fixing to the pack. | The block is 53 mm long, 88 mm wide and the full pack height, with four 15 x 7 mm channels lined up with the tendon exits. Each channel holds, from the back: the spool line's slack spring, the balance pulley (30 mm of travel against a 29.8 mm stroke) and the two finger lines' couplings side by side. Four M3 x 8 screws from inside the pack hold it to the front wall. A pocket underneath saves mass. | The channel holds the hardware that moves with the line; nothing fits beside it. Moving the pack toward the elbow (C8) keeps the block's front 7 mm short of the wrist. |
| C7 | The quick-release lever had no mechanism. | The eight sheath ends sit in four pucks in a cover on the front of the block. The pucks press on a red release plate in a 3.4 mm gap between block and cover. Pulling the plate's finger loop toward the thumb side slides it out (its two slots let it pass the tendons); the pucks and sheath ends then slide back into the channels and all eight tendons go slack at once. | One pull, by hand, no tools, at one place on the pack: the release does what the concept's lever was for. The form changed from a lever to a pull loop, so it is also listed for Amish's confirmation (Table 3, A1). |
| C8 | Knock-on of C1, C3, C5 and C6. | The pack is 168 mm long (was 160); its elbow end is 24 mm and its front 16 mm further toward the elbow; the cuff (still 174 mm long) moves 20 mm toward the elbow, ending 28 mm short of the elbow. | Room for the bulkhead, the spool hub, the encoder cable and the longer block without the block reaching the wrist. |
| C9 | Slack springs (eight) and stop beads (eight) had no place. | Four slack springs, one in each spool line behind its pulley. The eight stop beads are crimped on the tendons at the hand end, between each plate's stop block and the first cuff, where they stop against the block. | The balance pulley gives both tendons of a pair the same motion, so one spring per spool line takes up the same 1.2 mm mismatch. A bead at the hand end limits its finger to its own range exactly as before and is easy to set. |
| C10 | The finger cuffs were full 4.5 mm rings on fingers drawn 1.5 mm apart, so the cuffs of neighbouring fingers overlapped each other and the fingers; the tendons had no eyelets or end fixings; the cuffs had no way to close. | Cuffs and thimbles are padded saddles top and bottom over the same 62 % contact arc, with 1 mm TPU side bands; cuffs have a slit closed by a 6 mm hook-and-loop strip; eyelets and end tabs carry the tendons. The glove holds the fingers slightly spread (finger centres 24, 24 and 22.5 mm apart, was 19.5, 19.5 and 19). | Cuff widths and contact areas are unchanged, so the pressure results (R11) stand. The spread is how the device must be worn; it is also listed for confirmation with a therapist (Table 3, A2). |
| C11 | The sheaths ended on the hand plates with no stop, and the flexor sheaths passed through the wrist; the plates had no fixing to the glove. | Each plate carries a printed stop block with four ferrule seats; plates are stitched to the glove through rows of 1.5 mm holes. Sheath routes are redrawn: extensors over the back of the wrist, flexors down the side and under the wrist, none touching the hand, the glove or another sheath. | A sheath needs a seat at both ends to work; stitching is the usual way to fix a part to a glove. |
| C12 | The thumb spacer's block sat inside the thumb and the glove; the glove overlapped the forearm and fingers. | The spacer's ring moves 6 mm along the thumb and its block sits in the web space, shaped to the thumb and stitched to the glove's side. The glove ends at the wrist crease and the knuckles and has a thumb opening. | The spacer now holds the thumb out from outside it. |
| C13 | No fixings were listed. | BOM line 24, a fixing kit: 18 heat-set inserts, 26 screws and 8 steel pins; line 19 no longer covers fasteners. | Every joint names its fixing. |
| C14 | The couplings' 4 mm ball and spring (BOM line 10) cannot fit inside a body small enough for two couplings to sit side by side in a channel. | Each coupling is 6.8 mm across: two 2 mm steel balls in holes in the socket, pressed into a groove round the plug's stem by a ring of 0.4 mm spring wire. | Keeps a ball-detent breakaway on every tendon (N4) within the channel; the wire sets the pull-out force. |

*Table 2. Knock-on changes.*

| Item | Change | Reason |
| --- | --- | --- |
| Mass | Forearm pack about 723 g (was 639 g): pack base 105 g (was 79 g), anchor block parts 71 g printed (was 39 g), screws, inserts and pins 27 g (was 10 g allowed), tray 7 g, regulator 3 g. Hand side 117 g (was 115 g). R7: pack not met (further from 450 g), hand met [G2], [G4]. | Parts added for construction; the earlier fastener allowance was low. |
| Cost | Estimated cost of the constructable design USD 303.90 (was USD 289.90): lines 2, 15 and 19 repriced, lines 23 to 25 added. Value-engineering target USD 500: USD 196.10 under it [J1]. | Parts added for construction. |
| Drawing | FXH-DWG-001 Rev P3; making sketches FXH-DWG-101 to 116 added. | Follows the model. |
| Documents | FXH-CAL-001 v0.3, FXH-PRC-001 v0.5, FXH-REQ-001 v0.5: masses, cost wording, pack size and the release updated. No requirement changed status. | Follows the model. |
| Forces, speeds, energy, pressure | Unchanged: the spool radius, strokes, motors, cells, transmission and cuff contact areas are as before [A1] to [F3], [H2], [H3]. | |

*Table 3. Proposed, then accepted by Amish as recommended on 2026-10-02, with the conditions added in the recommendation column.*

| # | Question | Options | Recommendation |
| --- | --- | --- | --- |
| A1 | The tool-free release is now a pull-out plate with a finger loop, not a lever (C7). It changes the form of a safety feature, so Amish should confirm it. | (a) the pull-out plate, with its pull force and release time measured at TRL 4 against R9's 10 s; (b) a cam lever that drives the same plate out (more parts, lower pull force). | (a); move to (b) only if the measured pull force is too high for a care partner. Accepted 2026-10-02, with the pass mark set before the TRL 4 test: released in 10 s or less (R9) with a pull force that the co-design therapist agrees, before the test, a care partner can apply with one hand. |
| A2 | The cuffs need the fingers held slightly spread (C10). Spastic fingers may resist being spread. | (a) accept, and ask the co-design therapist (O1) to check it; (b) single-saddle cuffs that fit fingers at rest, with higher pressure (R11 at risk on the little finger). | (a). Accepted 2026-10-02 with a condition: nothing is worn until the co-design therapist has checked the spread on a range of hands with mild tone; switch to (b) if the spread raises tone or discomfort. |
| A3 | The pack is now about 723 g against the 450 g target of R7 (639 g before). | (a) keep the target under review with a therapist as already decided (N4 (c), waiting on O1) and weigh at TRL 4; (b) look for mass now (see the value-engineering savings in the register). | (a), with the savings in the register tried before TRL 4. Accepted 2026-10-02; the therapist review treats the pack mass as a safety question (load on a weak arm and shoulder). The listed savings come to about 30 to 60 g and cannot close the 273 g gap on their own. |

## Consequences

- `design_state: constructable` in `project.yaml`. The build plan FXH-BLD-001 shows every component and step in pictures generated from the model (`cad/src/build_plan_media.py`).
- Requirement status is unchanged in count: 1 not met (R7, now 723 g), 2 at risk (R2, R3), 7 met, 3 not verifiable at TRL 3 (FXH-CAL-001 v0.3). R12 is reported against the value-engineering target.
- The photoreal renders (`media/render-*.png`), `media/card.png`, `media/social-preview.png` and the appearance model `cad/src/product_model.py` still show the concept's pack, anchor block, lever and cuffs; they need updating on Amish's Mac, where Blender is.
- With A1 to A3 accepted: the release plate's pass mark is set before the TRL 4 test (10 s or less, with a pull force the co-design therapist agrees a care partner can apply one-handed), the cam lever being the fallback; nothing is worn until the therapist has checked the finger spread; the pack target stays under therapist review as a safety question. The build plan's release check and safety stop S6 carry these conditions (FXH-BLD-001 v0.2).
- Bought parts must be checked against the model when bought (gearbox face holes and shaft length, stop button depth, cell size, board sizes); these are listed in the design decisions register.

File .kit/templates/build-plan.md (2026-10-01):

---
doc_id: PRJ-BLD-001
title: Project prototype build plan
project: Project name
doc_type: Build plan
version: "0.1"
status: Draft
date: YYYY-MM-DD
author: Amish Chadha
license: CERN-OHL-S-2.0
revisions:
  - version: "0.1"
    date: YYYY-MM-DD
    author: Amish Chadha
    change: First build plan; design made constructable
---

# Project prototype build plan

**Plan, not yet built.** How to build the first proof-of-concept prototype, component by component. Building and testing to it is TRL 4 work. Decisions still to be made are kept in the design decisions register (`docs/06-design-decisions.md`), not here.

## 1. What you are building

Every component, pulled apart and numbered in build order

One short paragraph: what the prototype is, how many components, which are made and which are bought, and the main ways they are made.

## 2. What changed to make it buildable

| Component | The concept had | The buildable design has | Why |
| --- | --- | --- | --- |

## 3. Making the components

### 3.1 Component name

Making sketch

**What it is and what it is made from.**

**How to make it.**

1. Mark out ...
2. Cut ...

**How it fits the parts next to it.**

Close-up of the joint

**Check before moving on.**

## 4. Putting it together

### Step 1: ...

Step 1

## 5. First checks

| Check | Requirement | How | Pass when |
| --- | --- | --- | --- |

## 6. Safety stops

## 7. Tools, skills and workspace

## 8. Where the numbers come from

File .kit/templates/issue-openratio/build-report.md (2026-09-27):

---
name: Build report
about: Tell us what happened when you built, printed or tested part of this design
title: "Build report: "
labels: build-report
---

This is a research and educational prototype, not a medical device. It is a TRL 3 concept and is not released for fabrication. If you build any part of it, you do so at your own risk. Reports help everyone.

**What you built** (part, sub-assembly or test)

**Materials, tools and settings**

**What worked**

**What did not work, with photos or measurements if you have them**

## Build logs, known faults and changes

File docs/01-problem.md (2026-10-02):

---
doc_id: FXH-PRB-001
title: FlexHand problem statement
project: FlexHand
doc_type: Problem statement
version: "0.6"
status: Draft
date: '2026-10-02'
author: Amish Chadha
license: CERN-OHL-S-2.0
revisions:
- version: "0.1"
  date: '2026-09-24'
  author: Amish Chadha
  change: Initial scaffold
- version: "0.2"
  date: '2026-09-25'
  author: Amish Chadha
  change: Populate to TRL 2 (problem, users, context, constraints, prior work)
- version: "0.3"
  date: '2026-09-25'
  author: Amish Chadha
  change: Record decisions of FXH-DDR-001 (passive motion only, design load); complete the passive-mobilization citation; severity band finding from FXH-CAL-001
- version: "0.4"
  date: '2026-09-25'
  author: Amish Chadha
  change: Recommendations accepted by Amish (DDR-002); first severity band set to mild flexor tone
- version: "0.5"
  date: '2026-10-01'
  author: Amish Chadha
  change: Parts cost stated as a value-engineering target
- version: "0.6"
  date: '2026-10-02'
  author: Amish Chadha
  change: 'Open question on the first clinical partner answered by the decision of 2026-10-02 (FXH-DEC-001)'
---

# FlexHand problem statement

Recovery of hand function after stroke seems to depend on a large number of movement repetitions, but a typical therapy session delivers only a few dozen, and the rest of the day the affected hand often stays still and curled into flexion. FlexHand is a low-cost, open, wearable device that moves the fingers through hundreds of controlled flexion and extension cycles a day at home, within limits a therapist sets.

## The problem

Hand impairment is common and persistent after stroke. In a cohort of people who had a flaccid arm soon after stroke, only about 38 % had regained some dexterity at six months ([Kwakkel et al., *Stroke*, 2003](https://www.ahajournals.org/doi/full/10.1161/01.STR.0000087172.16305.CD)). Difficulty opening the hand is a large part of this impairment: finger extension deficits after stroke arise from both neural factors and changed muscle mechanics ([Kamper and Rymer, *Muscle & Nerve*, 2003](https://onlinelibrary.wiley.com/doi/10.1002/mus.10443)), and finger extension is typically affected more than flexion ([Soft pneumatic actuators for pushing fingers into extension, *JNER*, 2024](https://link.springer.com/article/10.1186/s12984-024-01444-4)).

Therapy dose is small. Lang and colleagues observed 312 physical and occupational therapy sessions and found an average of 32 repetitions of upper-limb functional movement per session, against the 400 to 600 repetitions per session used in animal models of recovery ([Lang et al., *Archives of Physical Medicine and Rehabilitation*, 2009](https://www.archives-pmr.org/article/S0003-9993(09)00353-0/abstract); [full text](https://epublications.marquette.edu/cgi/viewcontent.cgi?httpsredir=1&article=1073&context=phys_therapy_fac)). Therapist time is the limit, not the patient's day.

Devices that move the hand exist, but they are costly, clinic-bound or closed:

- Clinical robotic gloves such as Gloreha Sinfonia (now BTL R-TOUCH PRO) offer passive and active-assisted finger training, but they are tethered clinic systems ([Exoskeleton Report](https://exoskeletonreport.com/product/gloreha-sinfonia/)).
- The NEOFECT Smart Glove costs about $2,000 and tracks active movement for games; it does not move a hand that cannot move itself ([Recovery After Stroke](https://recoveryafterstroke.com/neofect-hand-rehabilitation/)).
- Research tendon-driven gloves show the approach works. The Columbia hand orthosis for stroke uses a single forearm-mounted gearmotor with about 100 N peak tendon force and a dorsal tendon network to extend four fingers ([Park et al., arXiv 1802.06131](https://arxiv.org/abs/1802.06131); [ROAM Lab](https://roam.me.columbia.edu/research-projects/hand-orthosis-stroke-rehabilitation)). Exo-Glove Poly II uses one actuator with antagonistic tendons and a 104 g polymer glove, but its actuation unit weighs about 1.14 kg and sits on a desk or wheelchair ([Kang et al., *Soft Robotics*, 2019](https://journals.sagepub.com/doi/10.1089/soro.2018.0006)).

No open, garage-buildable, wearable design exists that a clinic, a research group or a family can build, inspect and adapt for daily repetitive finger movement at home.

A caution sits at the center of this problem. Robotic passive mobilization has been studied mainly for short-term effects on spasticity and limb perfusion ([Gobbo et al., "Hand Passive Mobilization Performed with Robotic Assistance: Acute Effects on Upper Limb Perfusion and Spasticity in Stroke Survivors," *BioMed Research International*, 2017](https://onlinelibrary.wiley.com/doi/10.1155/2017/2796815); [PMC5637828](https://pmc.ncbi.nlm.nih.gov/articles/PMC5637828/)). Whether passive repetitions alone improve hand function is not established. FlexHand is a passive-motion device (decided by Amish, 2026-09-25, FXH-DDR-001, D3); active or intent-triggered modes are a later option, and it makes no therapeutic claim.

## Users and context

| User | Need | Context |
| --- | --- | --- |
| Stroke survivor with moderate hand impairment and mild flexor tone (MAS 1 to 1+) (subacute or chronic) | Many gentle, repeatable finger movements a day without waiting for a therapist | Home, seated with the forearm resting on a table or pillow; 30 to 60 min sessions, one to three a day |
| Care partner | Put the device on and take it off quickly and safely; know what to do if something goes wrong | Home |
| Occupational or physical therapist | Set range-of-motion, speed and force limits; see how many cycles were done | Clinic visit, then remote review |
| Researcher or open hardware community | A documented, reproducible platform to study dose and control strategies | University labs, makerspaces |

## Constraints

- Garage-buildable prototype, with a value-engineering target of USD 500 in parts (a control target, not a limit), using off-the-shelf motors and modules and 3D-printed parts.
- Wearable during a seated session: the hand side must be light and the actuators must sit on the forearm, not the hand.
- Fits a range of adult hands without custom molding.
- Safe with users who may have reduced sensation, spasticity and limited ability to remove the device themselves.
- Research and educational use only. FlexHand is not a medical device, has not been cleared or approved by any regulator, and must not be used to diagnose or treat any person outside a supervised research setting.

> **Safety:** The device applies force to joints that may be spastic, contracted or insensate, and it carries a lithium-ion battery. Force limits, a physical stop, a tool-free tendon release and supervised use are part of the problem definition, not extras.

## Out of scope

- Thumb actuation (the thumb is held in a passive abducted position in this concept).
- Wrist actuation.
- Diagnosis, assessment scoring or any therapeutic claim.
- Cloud services.

## Open questions

- Which clinical partner to co-design with first (a stroke unit occupational therapy team, a community rehabilitation service, or a university rehabilitation lab)? Decided 2026-10-02 (FXH-DEC-001): a university rehabilitation lab attached to a stroke service, introduced through the OpenRatio network; first candidate to approach: Shirley Ryan AbilityLab in Chicago, or a university rehabilitation program nearer Irving.
Decided on 2026-09-25 by Amish (FXH-DDR-001): passive motion only for this design, with active assist recorded as a later option (D3). The pitch is unchanged.

Decided on 2026-09-25 by Amish (FXH-DDR-002, N1): the first severity band is mild flexor tone (MAS 1 to 1+), which the 30 N design load covers according to the published finger stiffness check in FXH-CAL-001. Moderate and severe tone need roughly 80 to 150 N per finger and are left for a later design.

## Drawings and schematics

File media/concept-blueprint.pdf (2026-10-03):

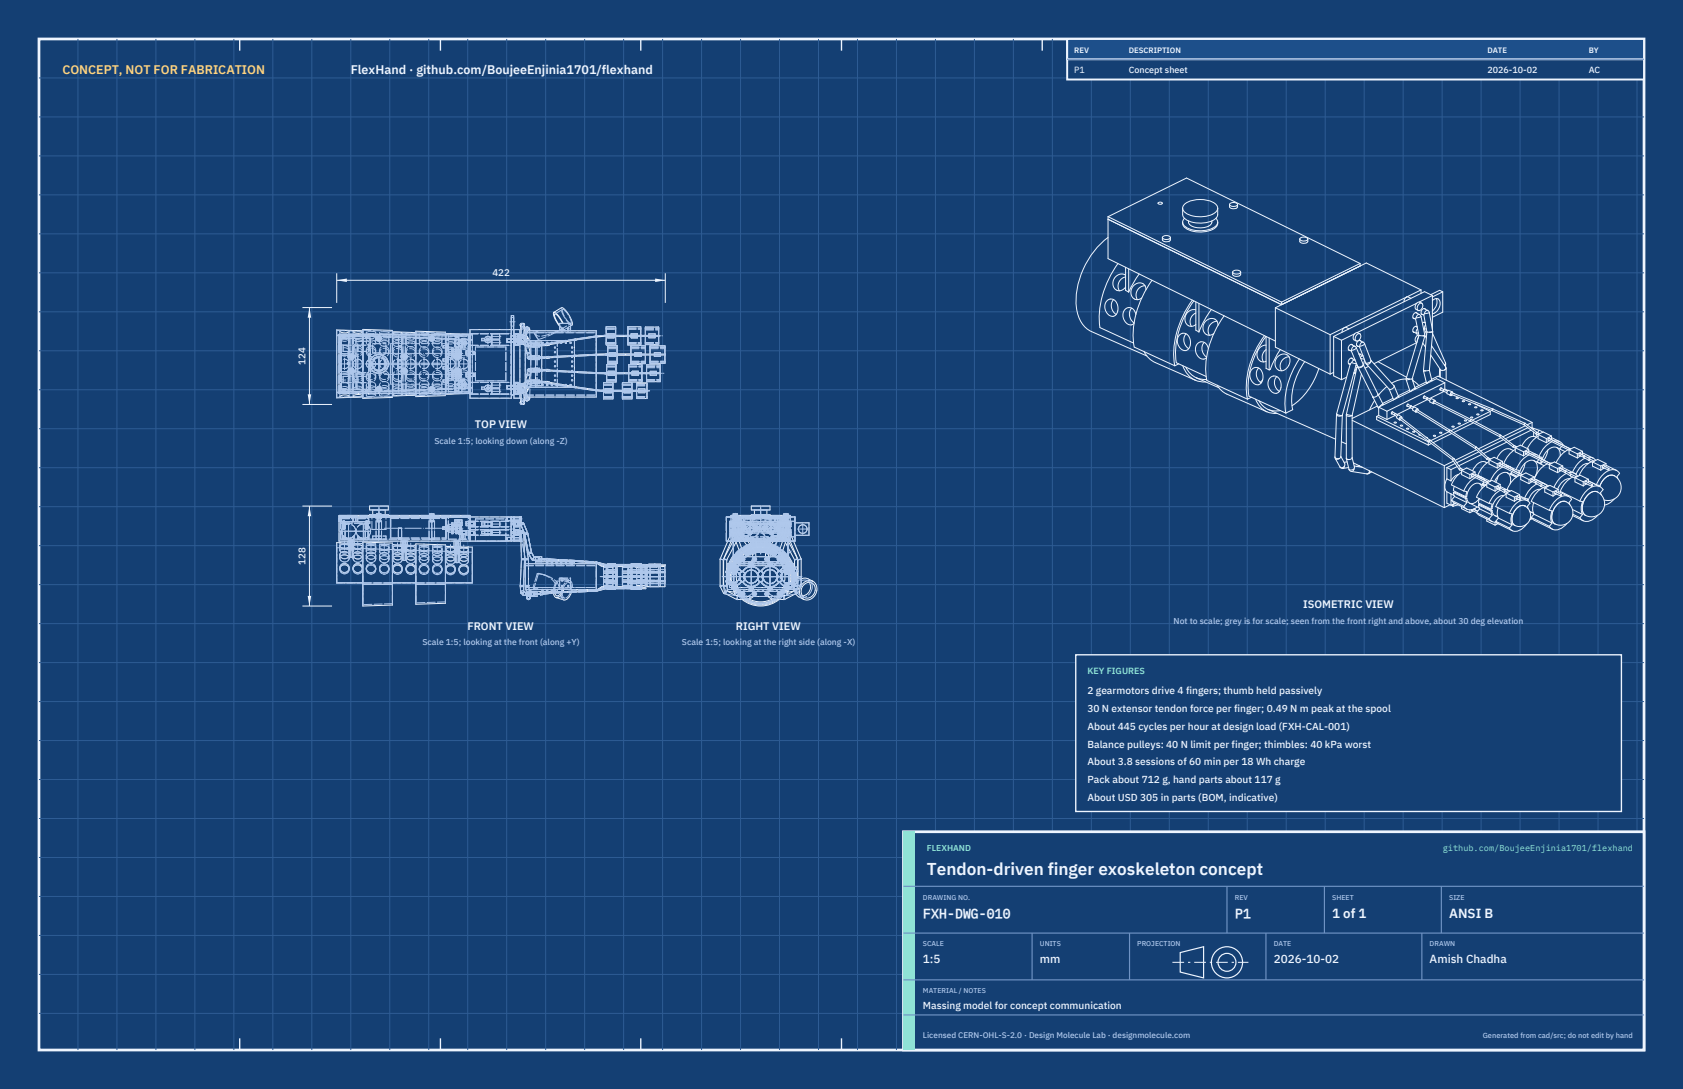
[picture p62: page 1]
CONCEPT, NOT FOR FABRICATION; FlexHand · github.com/BoujeeEnjinia1701/flexhand; FRONT VIEW; TOP VIEW; RIGHT VIEW; ISOMETRIC VIEW; REV; DESCRIPTION; DATE; Concept sheet; FLEXHAND; github.com/BoujeeEnjinia1701/flexhand; DRAWING NO. FXH-DWG-010; REV P1; SHEET 1 of 1; SIZE ANSI B; SCALE 1:5; UNITS mm; PROJECTION; DRAWN Amish Chadha; Licensed CERN-OHL-S-2.0 · Design Molecule Lab · designmolecule.com; Generated from cad/src; do not edit by hand

Scale 1:5; looking down (along -Z)

Not to scale; grey is for scale; seen from the front right and above, about 30 deg elevation

Scale 1:5; looking at the front (along +Y)

Scale 1:5; looking at the right side (along -X)

KEY FIGURES
2 gearmotors drive 4 fingers; thumb held passively
30 N extensor tendon force per finger; 0.49 N m peak at the spool
About 445 cycles per hour at design load (FXH-CAL-001)
Balance pulleys: 40 N limit per finger; thimbles: 40 kPa worst
About 3.8 sessions of 60 min per 18 Wh charge
Pack about 712 g, hand parts about 117 g
About USD 305 in parts (BOM, indicative)

Tendon-driven finger exoskeleton concept

MATERIAL / NOTES
Massing model for concept communication

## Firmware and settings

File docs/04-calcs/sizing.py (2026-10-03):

"""FlexHand sizing calculations (FXH-CAL-001 v0.3: decisions of FXH-DDR-002 and the constructable design of FXH-DDR-003).

Run from the repo root:  python docs/04-calcs/sizing.py
Prints every number quoted in docs/04-calcs/01-sizing.md, tagged [A1], [B2] and so on.
Geometry comes from cad/src/model.py; costs come from bom/bom.csv; the budget from project.yaml.
First-principles estimates for a paper proof of concept (TRL 3). Not a test result.
"""
import csv
import sys
from math import exp, pi, radians, degrees
from pathlib import Path

ROOT = Path(__file__).resolve().parents[2]
sys.path.insert(0, str(ROOT / "cad" / "src"))

# ---------------- assumptions (see Table 1 of the note) ----------------
F_DESIGN = 30.0          # N, extensor tendon force per finger at full extension (R2, D5)
F_START = 3.0            # N, per finger at the start of extension (friction, slack spring)
F_FLEX = 5.0             # N, per finger while flexing (extensor passive tone, slack spring, cuff friction)
FINGERS_PER_MOTOR = 2    # D2: one motor per finger pair
R_MCP, R_PIP = 10.0, 8.0         # mm, dorsal (extensor) moment arms
R_MCP_F, R_PIP_F = 11.0, 8.0     # mm, palmar (flexor) moment arms
ROM_MCP, ROM_PIP = 70.0, 90.0    # deg, R1 range
COMPLIANCE = 5.0                 # mm, cuff and liner take-up at design load, added to the stroke
MU, BEND = 0.10, pi              # sheath friction coefficient and total bend (rad), neutral wrist
MU_HI, BEND_HI = 0.15, 1.5 * pi  # pessimistic case: worn liner, flexed wrist
ETA_IDLER = 0.95                 # one idler bearing per tendon line
ETA_BALANCE = 0.95               # N3 (DDR-002): one floating balance pulley per spool line
STROKE_MIN_DESIGN = 4.0          # s, N5 (DDR-002): lower stroke-time limit at design load (R5)
DWELL = 1.0                      # s at each end
# Gearmotor: Pololu 4869, 227:1 25D MP 12 V with 48 CPR encoder (datasheet at 12 V)
V_RATED, I_STALL, I_NL, RPM_NL, T_STALL = 12.0, 1.8, 0.10, 35.0, 24 * 0.0980665   # T in N·m
T_CONT, T_INT = 4 * 0.0980665, 8 * 0.0980665          # recommended continuous and intermittent load
M_MOTOR = 107.0                                         # g, datasheet
V_BUS = 7.2              # V, 2S pack under load, less driver drop
P_CTRL = 0.40            # W, ESP32-S3, drivers idle, LED, regulator
CELL_WH = 2.5 * 3.6      # Wh per 18650 cell (2,500 mAh, 3.6 V)
N_CELLS, USABLE = 2, 0.80
HOLD_AT_EXTENSION = True # conservative: hold full torque with current during the extended dwell
# Stiffness of post-stroke fingers, Heung et al. 2020 (Front. Bioeng. Biotechnol. 8:111)
K_MAS1P = (0.089, 0.092)     # N·m/rad, MCP and PIP, subject with MAS 1+
K_MAS3 = (0.631, 0.753)      # N·m/rad, MCP and PIP, subject with MAS 3
# Contact pressure
P_LIMIT = 50.0           # kPa, R11
# Densities (g/cm3) and bought-part masses (g)
RHO_PETG, RHO_TPU, RHO_PA12, RHO_EVA, RHO_LINER = 1.27, 1.21, 1.01, 0.07, 0.20
RHO_STEEL, RHO_BRASS, RHO_ALU = 7.85, 8.5, 2.70   # aluminium for the lid and cover screws (2026-10-02 savings)
FILL_BLOCK = 0.40        # infill share for the solid-looking anchor block
MASS = {"cell": 45.0, "bms": 5.0, "controller": 3.0, "driver": 3.0, "charger": 4.0, "estop": 20.0,
        "idler": 1.5, "balance": 1.5, "coupling": 2.0,   # N4: ball-detent breakaway (magnetic was 7.0 g)
        "coupling_magnetic": 7.0, "slack_spring": 1.0, "strap": 8.0, "wiring": 15.0, "regulator": 3.0,
        "stop_bead": 0.1,
        "glove": 40.0, "sheath_g_per_m": 25.0, "ferrule": 0.5, "tendon_g_per_m": 0.45}
BYTES_PER_SESSION, FLASH_LOG_BYTES = 32, 1_000_000


def motor_model(v):
    """Output-shaft DC model from the 12 V datasheet points. Returns (R, kt, ke, stall torque at v)."""
    R = V_RATED / I_STALL
    kt = T_STALL / (I_STALL - I_NL)                       # N·m per A above no-load current
    ke = (V_RATED - I_NL * R) / (RPM_NL * 2 * pi / 60)     # V per rad/s at the output
    return R, kt, ke, (v / R - I_NL) * kt


def stroke(force_fn, travel_mm, eta, r_m, v=V_BUS, n=400):
    """Full-voltage stroke. force_fn(s) gives force per finger at travel s (mm). Returns dict."""
    R, kt, ke, _ = motor_model(v)
    t = e_el = e_shaft = e_fing = 0.0
    tq = []
    ds = travel_mm / n
    for i in range(n):
        s = (i + 0.5) * ds
        f = FINGERS_PER_MOTOR * force_fn(s)             # N at the fingers
        T = f / eta * r_m                              # N·m at the spool
        I = I_NL + T / kt
        w = (v - I * R) / ke                           # rad/s
        dt = (ds / 1000) / (w * r_m)
        t += dt; e_el += v * I * dt; e_shaft += T * w * dt; e_fing += f * ds / 1000
        tq.append((T, dt))
    return dict(t=t, e_el=e_el, e_shaft=e_shaft, e_fing=e_fing, tq=tq)


def compute():
    import model
    m = model.build_parts()
    d, parts, sub = m["d"], m["parts"], m["sub"]
    R = {}

    # ---- A. Excursion (R1) ----
    ext = R_MCP * radians(ROM_MCP) + R_PIP * radians(ROM_PIP)
    flx = R_MCP_F * radians(ROM_MCP) + R_PIP_F * radians(ROM_PIP)
    travel = ext + COMPLIANCE
    r_eff = d["spool_r_eff"] / 1000
    cap = 2 * pi * d["spool_r_eff"] * (d["spool_w"] / 2 - 1.5) / (d["tendon_d"] * 2)   # one layer, per line
    R.update(ext=ext, flx=flx, mismatch=flx - ext, travel=travel, spool_turns=travel / (2 * pi * d["spool_r_eff"]),
             groove_cap=cap)

    # ---- B. Design load against published stiffness (R2 basis) ----
    def need(k):
        return max(k[0] * radians(ROM_MCP) / (R_MCP / 1000), k[1] * radians(ROM_PIP) / (R_PIP / 1000))
    R.update(F_mas1p=need(K_MAS1P), F_mas3=need(K_MAS3),
             k_cover=F_DESIGN * (R_PIP / 1000) / radians(ROM_PIP))

    # ---- C. Transmission and torque (R2) ----
    eta = exp(-MU * BEND) * ETA_IDLER * ETA_BALANCE
    eta_hi = exp(-MU_HI * BEND_HI) * ETA_IDLER * ETA_BALANCE
    F_spool = FINGERS_PER_MOTOR * F_DESIGN / eta
    T_peak = F_spool * r_eff
    T_peak_hi = FINGERS_PER_MOTOR * F_DESIGN / eta_hi * r_eff
    Rm, kt, ke, T_st = motor_model(V_BUS)
    R.update(eta=eta, eta_hi=eta_hi, F_spool=F_spool, T_peak=T_peak, T_peak_hi=T_peak_hi, T_cont=T_CONT,
             T_int=T_INT, T_stall_bus=T_st, Rm=Rm, kt=kt, ke=ke)

    # ---- D. Speed, cycle and dose (R4, R5) ----
    ext_fn = lambda s: F_START + (F_DESIGN - F_START) * min(s / travel, 1.0)
    se = stroke(ext_fn, travel, eta, r_eff)
    sf = stroke(lambda s: F_FLEX, travel, eta, r_eff)
    se_hi = stroke(ext_fn, travel, eta_hi, r_eff)
    cycle = se["t"] + sf["t"] + 2 * DWELL
    w_nl = (V_BUS - I_NL * Rm) / ke
    R.update(t_ext=se["t"], t_flex=sf["t"], t_ext_hi=se_hi["t"], cycle=cycle, cycles_per_min=60 / cycle,
             cycles_per_h=3600 / cycle, rpm_nl_bus=w_nl * 60 / (2 * pi), v_tendon_nl=w_nl * r_eff * 1000,
             t_noload=travel / (w_nl * r_eff * 1000), mcp_speed=ROM_MCP / se["t"], pip_speed=ROM_PIP / se["t"],
             max_stroke_for_R4=(3600 / 300 - 2 * DWELL) / 2,
             cycles_per_h_min=3600 / (2 * STROKE_MIN_DESIGN + 2 * DWELL))
    # RMS spool torque over a cycle (hold at extension counted at peak torque)
    num = sum(T * T * dt for T, dt in se["tq"] + sf["tq"]) + (T_peak ** 2) * DWELL
    R["T_rms"] = (num / cycle) ** 0.5

    # ---- E. Force limit (R3) ----
    T_lim_pair = FINGERS_PER_MOTOR * 40.0 / eta * r_eff
    I_lim = I_NL + T_lim_pair / kt
    f_est_lo, f_est_hi = 40.0 * eta_hi / eta, 40.0 * exp(-0.05 * pi) * ETA_IDLER * ETA_BALANCE / eta
    # N3: the balance pulley keeps both tendons of a pair at the same tension, so the pair limit is also
    # the per-finger limit (was: one finger up to the whole pair force, 80 N, with the partner slack)
    R.update(I_lim=I_lim, T_lim_pair=T_lim_pair, I_peak=I_NL + T_peak / kt,
             F_single_at_limit=T_lim_pair / r_eff * eta / FINGERS_PER_MOTOR,
             F_single_no_balance=FINGERS_PER_MOTOR * 40.0, f_est_lo=f_est_lo, f_est_hi=f_est_hi,
             balance_travel=d["balance_travel"], travel_free=FINGERS_PER_MOTOR * travel)

    # ---- F. Energy (R6) ----
    I_hold = I_NL + T_peak / kt
    e_hold = V_BUS * I_hold * DWELL if HOLD_AT_EXTENSION else 0.0
    e_cycle_motor = se["e_el"] + sf["e_el"] + e_hold
    cyc = R["cycles_per_h"]
    E_motor = 2 * e_cycle_motor * cyc / 3600          # Wh per 60 min session, both motors
    E_shaft = 2 * (se["e_shaft"] + sf["e_shaft"]) * cyc / 3600
    E_finger = 2 * (se["e_fing"] + sf["e_fing"]) * cyc / 3600
    E_ctrl = P_CTRL * 1.0
    E_session = E_motor + E_ctrl
    pack_wh = N_CELLS * CELL_WH
    R.update(e_ext=se["e_el"], e_flex=sf["e_el"], e_hold=e_hold, I_hold=I_hold, E_motor_Wh=E_motor,
             E_shaft_Wh=E_shaft, E_finger_Wh=E_finger, E_ctrl_Wh=E_ctrl, E_session_Wh=E_session,
             P_avg=E_session, pack_Wh=pack_wh, usable_Wh=pack_wh * USABLE,
             sessions=pack_wh * USABLE / E_session, I_avg=E_session / V_BUS)

    # ---- G. Mass (R7) ----
    v = lambda s: s.volume / 1000.0          # cm3
    C = m["c"]
    sheath_len = sum(Lp for _, _, Lp in m["sheath_paths"]) * d["sheath_slack"] / 1000   # m
    m_sheaths = sheath_len * MASS["sheath_g_per_m"] + 16 * MASS["ferrule"]
    steel = sum(v(C[k]) for k in ("cuff_screws", "motor_screws", "tray_screws",
                                    "anchor_screws", "idler_pins", "balance_pins"))
    alu = sum(v(C[k]) for k in ("lid_screws", "cover_screws"))        # aluminium M3 screws, light loads only
    m_fix = steel * RHO_STEEL + alu * RHO_ALU + v(C["inserts"]) * RHO_BRASS
    m_fix_steel_all = (steel + alu) * RHO_STEEL + v(C["inserts"]) * RHO_BRASS
    pack = {
        "Forearm cuff shell (PETG)": v(sub["cuff_shell"]) * RHO_PETG,
        "Cuff liner (EVA foam)": v(sub["cuff_liner"]) * RHO_EVA,
        "Straps (2)": 2 * MASS["strap"],
        "Pack base (PETG)": v(C["pack_base"]) * RHO_PETG,
        "Pack lid (PETG)": v(C["pack_lid"]) * RHO_PETG,
        "Electronics tray (PETG)": v(C["tray"]) * RHO_PETG,
        "Gearmotors (2)": 2 * M_MOTOR,
        "Spools (2, PA12)": v(C["spools"]) * RHO_PA12,
        "Idler bearings (4)": 4 * MASS["idler"],
        "Cells (2) and BMS": N_CELLS * MASS["cell"] + MASS["bms"],
        "Controller, drivers, charger, regulator": MASS["controller"] + 2 * MASS["driver"] + MASS["charger"] + MASS["regulator"],
        "Emergency stop": MASS["estop"],
        "Anchor block, release plate, cover, pucks": (v(C["anchor_body"]) * FILL_BLOCK + v(C["gate"]) + v(C["cover"])
                                                       + v(C["pucks"])) * RHO_PETG,
        "Couplings (8) and slack springs (4)": 8 * MASS["coupling"] + 4 * MASS["slack_spring"],
        "Balance pulleys (4)": 4 * MASS["balance"],
        "Wiring": MASS["wiring"],
        "Screws, inserts and pins": m_fix,
        "Sheaths, half": m_sheaths / 2,
    }
    tendon_len = 8 * 0.40 + 4 * 0.03          # extensors run on about 30 mm to the thimble
    hand = {
        "Base glove (bought)": MASS["glove"],
        "Dorsal and palmar plates with stop blocks (TPU)": (v(C["dorsal_plate"]) + v(C["palmar_plate"])) * RHO_TPU,
        "Finger cuffs (8, TPU)": v(C["finger_cuffs"]) * RHO_TPU,
        "Cuff liners": v(C["cuff_liners"]) * RHO_LINER,
        "Fingertip thimbles (4, TPU)": v(C["thimbles"]) * RHO_TPU,
        "Thimble liners": v(C["thimble_liners"]) * RHO_LINER,
        "Thumb spacer (TPU)": v(C["thumb_spacer"]) * RHO_TPU,
        "Tendons and stop beads": tendon_len * MASS["tendon_g_per_m"] + 8 * MASS["stop_bead"],
        "Sheaths, half": m_sheaths / 2,
    }
    R.update(mass_pack=pack, mass_hand=hand, m_pack=sum(pack.values()), m_hand=sum(hand.values()),
             sheath_len=sheath_len, m_sheaths=m_sheaths, m_motors=2 * M_MOTOR, m_fix=m_fix, m_fix_saved=m_fix_steel_all - m_fix,
             m_couplings=8 * MASS["coupling"], m_couplings_saved=8 * (MASS["coupling_magnetic"] - MASS["coupling"]),
             m_cuff_perf_saved=(v(sub["cuff_shell_solid"]) - v(sub["cuff_shell"])) * RHO_PETG,
             cuff_open_frac=1 - v(sub["cuff_shell"]) / v(sub["cuff_shell_solid"]))

    # ---- H. Cuff pressure (R11) and fit (R10) ----
    rows = []
    names = ["Index", "Middle", "Ring", "Little"]
    # N2: the extensor load is shared by the middle-phalanx anchor cuff and the fingertip thimble;
    # assumed shared in proportion to contact area (equal mean pressure), to check at TRL 4
    for nm, fg in zip(names, d["finger_geom"]):
        area = fg["anchor_w"] * fg["arc"]
        rows.append(dict(name=nm, lm=fg["lm"], usable=fg["usable"], w=fg["anchor_w"], arc=fg["arc"],
                         tw=fg["thimble_w"], ld=fg["ld"],
                         p_cuff=F_DESIGN / area * 1000, p20=F_DESIGN / (20 * fg["arc"]) * 1000,
                         p=F_DESIGN / ((fg["anchor_w"] + fg["thimble_w"]) * fg["arc"]) * 1000))
    R["cuffs"] = rows
    R["p12"] = F_DESIGN / (12 * 25) * 1000                       # TRL 2 basis: 12 mm x 25 mm
    R["hand_length"] = d["hand_length"]
    sizes = {}
    for sz, hl in (("S", 170.0), ("M", d["hand_length"]), ("L", 205.0)):
        k = hl / d["hand_length"]
        lit = d["finger_geom"][3]
        usable = lit["lm"] * k - 2 * d["joint_clear"]
        tw = min(d["thimble_w_max"], lit["ld"] * k - d["joint_clear"])
        arc = lit["arc"] * k
        sizes[sz] = dict(k=k, little_usable=usable, little_tw=tw,
                         little_p_cuff=F_DESIGN / (min(20, usable) * arc) * 1000,
                         little_p=F_DESIGN / ((min(20, usable) + tw) * arc) * 1000)
    R["sizes"] = sizes

    # ---- I. Stop (R9) ----
    C_bulk, dV = 100e-6, V_BUS
    R["t_holdup_ms"] = C_bulk * dV / (2 * I_hold) * 1000
    R["t_bounce_ms"] = 5.0
    R["t_stop_ms"] = R["t_holdup_ms"] + R["t_bounce_ms"] + 5.0      # plus 5 ms rotor run-down (estimate)

    # ---- J. Cost (R12) ----
    with (ROOT / "bom" / "bom.csv").open() as fh:
        bom = list(csv.DictReader(fh))
    R["bom_lines"] = len(bom)
    R["bom_total"] = sum(float(r["qty"]) * float(r["unit_cost_usd"]) for r in bom)
    import yaml
    R["budget"] = float(yaml.safe_load((ROOT / "project.yaml").read_text())["budget_usd"])

    # ---- K. Log (R13) ----
    R["log_days"] = FLASH_LOG_BYTES / (BYTES_PER_SESSION * 3)
    return R


def status_table(R):
    c = {r["name"]: r for r in R["cuffs"]}
    worst = max(r["p"] for r in R["cuffs"])
    worst_all = max(max(r["p"] for r in R["cuffs"]), max(s["little_p"] for s in R["sizes"].values()))
    st = lambda ok, bad="not met": "met" if ok else bad
    return [
        ("R1", "Finger range (tendon excursion)", f"{R['ext']:.1f} mm needed; {R['travel']:.1f} mm stroke", "25 mm for MCP 70°, PIP 90°", "met"),
        ("R2", "Extend against mild flexor tone", f"30 N covers {R['F_mas1p']:.0f} N needed at MAS 1+; {R['T_peak']:.3f} N·m peak, {R['T_rms']:.3f} N·m RMS at the spool", f"30 N per finger (MAS 1 to 1+); gearbox {T_CONT:.2f} N·m continuous, {T_INT:.2f} N·m intermittent", "at risk" if R['T_peak'] > T_CONT else "met"),
        ("R3", "Limit force on the hand", f"{R['I_lim']:.2f} A trip; balance pulley holds each finger to {R['F_single_at_limit']:.0f} N; friction spread {R['f_est_lo']:.0f} to {R['f_est_hi']:.0f} N", "40 N per finger (software); 60 N breakaway", "at risk"),
        ("R4", "Repetition dose", f"{R['cycles_per_h']:.0f} cycles per hour at full speed; {R['cycles_per_h_min']:.0f} at {STROKE_MIN_DESIGN:.0f} s strokes", "300 or more per 60 min", st(R['cycles_per_h_min'] >= 300)),
        ("R5", "Slow, smooth, adjustable stroke", f"fastest {R['t_ext']:.1f} s at design load ({R['t_ext_hi']:.1f} s pessimistic), {R['t_noload']:.1f} s unloaded", f"{STROKE_MIN_DESIGN:.0f} to 15 s at design load", st(R['t_ext_hi'] <= STROKE_MIN_DESIGN, "at risk")),
        ("R6", "Sessions per charge", f"{R['sessions']:.1f} sessions ({R['E_session_Wh']:.2f} Wh each)", "3 or more", "met"),
        ("R7", "Mass", f"hand {R['m_hand']:.0f} g; pack {R['m_pack']:.0f} g", "hand 120 g or less; pack 450 g or less", st(R['m_hand'] <= 120 and R['m_pack'] <= 450)),
        ("R8", "Donning and removal time", "not calculable", "5 min on, 1 min off", "not verifiable at TRL 3"),
        ("R9", "Stop and release", f"power cut in about {R['t_stop_ms']:.0f} ms; release by design", "100 ms; release in 10 s", "not verifiable at TRL 3"),
        ("R10", "Fit adult hands", "S, M, L glove sizes scaled from the model", "hand length 170 to 205 mm", "met"),
        ("R11", "Cuff contact pressure", f"cuff and thimble: {worst:.0f} kPa worst on the medium hand (little finger); index {c['Index']['p']:.0f}, middle {c['Middle']['p']:.0f}, ring {c['Ring']['p']:.0f}; {worst_all:.0f} kPa worst over S to L", "50 kPa or less", st(worst_all <= P_LIMIT)),
        ("R12", "Parts cost", f"USD {R['bom_total']:.2f}", f"value-engineering target USD {R['budget']:.0f}",
         f"under the target by USD {R['budget'] - R['bom_total']:.2f}" if R['bom_total'] <= R['budget'] else f"over the target by USD {R['bom_total'] - R['budget']:.2f}"),
        ("R13", "Session log", f"about {R['log_days']:,.0f} days of summaries in 1 MB of flash", "time, cycles, peak current; locked limits", "not verifiable at TRL 3"),
    ]
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

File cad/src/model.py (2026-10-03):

"""FlexHand parametric model (build123d), constructable design (FXH-DDR-003).

Run from the repo root:
    python cad/src/model.py            export STEP and STL into cad/step and cad/stl
    python cad/src/model.py --check    run the constructability checks (overlaps, contacts, fixings)

Axes (right forearm and hand, palm down): X runs from the elbow toward the fingertips with
the wrist at X = 0, Y is across the forearm with +Y on the thumb (radial) side, Z is dorsal (up).
A left-hand device is the mirror image about the XZ plane.

Every part is modelled as it is made: printed parts with their holes, bosses and pockets, bought
parts at their catalogue sizes, and the fixings that join them. The forearm and hand are context.
components() returns the parts one by one (for the build plan pictures and the checks);
build_parts() groups them by bill of materials line (for the media, drawings and calculations).
PRELIMINARY, NOT FOR FABRICATION.
"""
from math import cos, pi, radians, sin, sqrt
from pathlib import Path

# Top-level parameters (mm). Edit these, not the geometry below.
PARAMS = {
    # ---- context anthropometry (adult, medium glove size, hand length about 183 mm) ----
    "arm_l": 270.0, "r_elbow": 38.0, "r_wrist": 29.0,
    "palm_l": 95.0, "palm_w": 80.0, "palm_t": 28.0,
    # finger (lateral y, length from MCP, radius); index, middle, ring, little.
    # DDR-003 C9: fingers held slightly spread by the glove so the cuffs of neighbouring fingers clear
    "fingers": [(36.0, 80.0, 9.0), (12.0, 88.0, 9.0), (-12.0, 82.0, 8.5), (-34.5, 65.0, 7.5)],
    "phalanx_frac": (0.47, 0.28, 0.25),   # proximal, middle, distal share of finger length (assumed)
    "thumb_o": (15.0, 38.0, -6.0), "thumb_d": (0.83, 0.5, -0.25), "thumb_l": 62.0, "thumb_r": 10.5,
    # ---- forearm cuff (item 1) ----
    "cuff_x": (-242.0, -68.0), "cuff_t": 2.0, "liner_t": 4.0, "strap_w": 38.0, "strap_x": (-189.5, -121.5),
    "strap_t": 1.8, "cuff_edge_z": -8.0,
    # perforated cuff shell and liner (N4): radial holes on a grid (x start, x end, x step; angles from dorsal)
    "cuff_hole_d": 12.0, "cuff_hole_x": (-232.0, -78.0, 17.0), "cuff_hole_ang": (-75.0, -50.0, -25.0, 0.0, 25.0, 50.0, 75.0),
    # pack saddle ribs sit on the solid webs between hole columns; two M3 screws per rib (C1)
    "rib_x": (-223.5, -155.5, -87.5), "rib_t": 3.0, "rib_boss_y": 9.0, "rib_boss_d": 8.0,
    # ---- motor pack (items 2 to 10, 18, 20, 23, 25) ----
    "pack_x": (-239.0, -71.0),    # rear and front wall outer faces (C2)
    "pack_w": 76.0,               # outer width across the forearm
    "floor_z": 48.0,              # top of the pack floor (cavity bottom); raised 4 mm (C1)
    "wall": 2.0, "floor_t": 2.5, "lid_t": 2.0,
    "motor_d": 25.0, "motor_l": 71.0,          # 25D x 71L gearmotor with encoder (Pololu 4869 class)
    "shaft_l": 12.5, "shaft_d": 4.0, "face_hole_pitch": 17.0,   # two M3 holes in the gearbox face
    "motor_y": 13.5,                            # motor axes at y = +/- motor_y (C3)
    "motor_x0": -172.8,                         # rear end of the motor bodies
    "cable_gap": 6.0,                           # room behind the motors for the encoder cable
    "bulkhead_t": 3.0,                          # motor bulkhead printed in the pack base (C3)
    "spool_core_d": 10.0, "spool_flange_d": 14.0, "spool_w": 12.0, "spool_hub_l": 4.0, "tendon_d": 0.8,
    "flange_t": 1.5,
    "idler_d": 10.0, "idler_w": 4.0, "idler_bore": 3.0,   # 623ZZ-class bearings used as idlers, axis Z
    "line_y": 31.25,                            # where each spool line leaves its idler and the pack (C4)
    "cell_d": 18.4, "cell_l": 65.0, "cell_x": (-226.8, -207.8),   # two 18650 cells, axes across (Y) (C5)
    "estop_x": -187.8, "estop_d": 18.0, "estop_depth": 18.0, "estop_cap_d": 24.0,
    "lid_boss_x": (-188.0, -120.0), "lid_boss_y": 32.5,
    # ---- anchor block (item 10) and sheaths (item 11) (C6, C7) ----
    "anchor_l": 53.0, "anchor_h": 26.0, "anchor_w": 88.0,
    "gate_t": 3.0, "cover_l": 7.6, "puck": (5.0, 14.0, 6.0),
    "chan_w": 15.0, "chan_h": 7.0,
    "balance_d": 8.0, "balance_w": 4.0,         # 693ZZ-class bearings used as floating balance pulleys, axis Z
    "balance_y": 31.25,
    "coupling_d": 6.8, "coupling_l": 10.0, "spring_l": 4.0,
    "sheath_od": 4.0, "sheath_slack": 1.2,      # cut length = neutral path x slack factor
    # ---- hand side (items 12 to 17, 21) ----
    "glove_t": 2.5, "plate_t": 2.5,
    "guide_cuff_w": 12.0,                       # proximal (guide) cuff width
    "anchor_cuff_w_max": 20.0,                  # D4: 20 mm anchor cuffs where the phalanx allows
    "thimble_w_max": 20.0,                      # N2 (DDR-002): open-tip fingertip thimble on the distal phalanx
    "thimble_t": 2.0,                           # thimble TPU wall (liner as for the cuffs)
    "joint_clear": 3.0,                         # clearance from each joint crease to a cuff edge
    "cuff_t": 2.5, "cuff_liner_t": 2.0,
    "contact_arc_frac": 0.62,                   # share of finger circumference in contact under load
    "side_band_t": 1.0,                         # thin TPU side band between the padded saddles (C9)
    "stop_y": (24.0, 8.0, -8.0, -23.0),         # sheath stops on the hand plates, index to little
}
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

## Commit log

2026-09-24 Initial scaffold: standard open hardware layout, CERN-OHL-S v2 + MIT licenses
    Claude-Session: https://claude.ai/code/session_01XuhhSU4W6fYhgCfURbrkut
    [bom.csv]
2026-09-25 Adopt portfolio kit v1.3.0: session commands, scale figure, 3D viewer, flow diagrams
    Adds .claude/commands (/populate, /advance-trl3, /rein-in, /refresh-media)
    so every Claude Code session starts from the standard prompts, and extends
    concept media with a 1.75 m scale figure, an interactive glTF viewer and
    system or energy flow diagrams. TRL cap 3 unchanged.
    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
2026-09-25 Kit v1.3.1: renderer fixes from the TremorTrace pilot
    Context scale parts for small objects, cutaway exclusions, and text
    labels in flow diagrams.
    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
2026-09-25 Populate flexhand to a strong TRL 2 with concept media (overnight batches 4 and 5)
    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
    [bom.csv]
2026-09-25 Advance flexhand to TRL 3 (batch 4)
    Decisions approved by Amish 2026-09-25 recorded in DDR-001. TRL 4 is on hold.
    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
    [bom.csv, flexhand-anchor-block.step, flexhand-anchor-block.stl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]
2026-09-26 Accept all recommendations (DDR-002), switch footer to designmolecule.com, add README write-up with new inspiration point
    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
    [bom.csv, flexhand-anchor-block.step, flexhand-anchor-block.stl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]
2026-09-27 Product appearance model and photoreal renders
    Adds cad/src/product_model.py (appearance model for renders only, all main
    dimensions from model.py) and Blender renders in media/render-*.png,
    captioned with the project, repository and viewing direction. README leads
    with the product render; trl stays 3.
    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
2026-10-01 Image quality pass: legible exploded views, flow diagrams and drawing sheets
    Kit 1.6.1 image layout: the parts list sits in its own column, number bubbles sit on visible parts and never overlap, small parts get a leader, pictures are cropped to the subject, flow labels keep numbers with their units, and sheet captions and the revision table no longer overprint. Concept images, blueprint and general arrangement sheet regenerated; repo-specific labels moved clear of other text and lines.
2026-10-01 Kit 1.7.0: constructable design, illustrated build plan and design decisions register
    The design is now constructable: every part can be made and fits its neighbours, with each change recorded in a Design for construction decision record (made under Amish's 2026-09-30 instruction; ope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
    FlexHand also credits Dr. Geeti Chadha as a contribut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
    [bom.csv, flexhand-anchor-body.step, flexhand-anchor-body.stl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]
2026-10-02 Record Amish's approval of the open-decision recommendations
    Amish approved the recommendation on every open decision in the design decisions register ("i approve your recommendations for all 555 open decisions.", 2026-10-02). Each decision is moved to Decisio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
2026-10-03 Carry approved follow-ups into the design and redo photoreal renders
    Amish approved the follow-up actions from the open-decision sign-off ("APPROVED CHANGES, COMPLETE THESE", 2026-10-02), the design-for-construction change tables in ten repos, the last wave's open dec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
    [bom.csv, flexhand-anchor-body.step, flexhand-anchor-body.stl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]

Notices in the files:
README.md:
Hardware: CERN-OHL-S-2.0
